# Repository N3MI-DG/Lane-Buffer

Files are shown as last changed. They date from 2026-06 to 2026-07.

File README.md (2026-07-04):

# Lane Buffer for Boxturtle
An inline filament buffer for toolchangers integrated into the rear skirts of the Boxturtle.

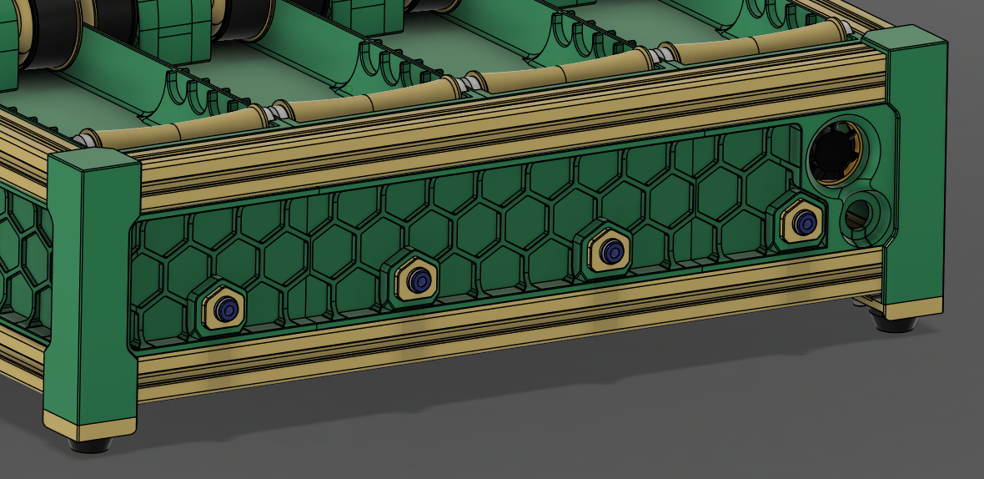
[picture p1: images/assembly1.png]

<br/>
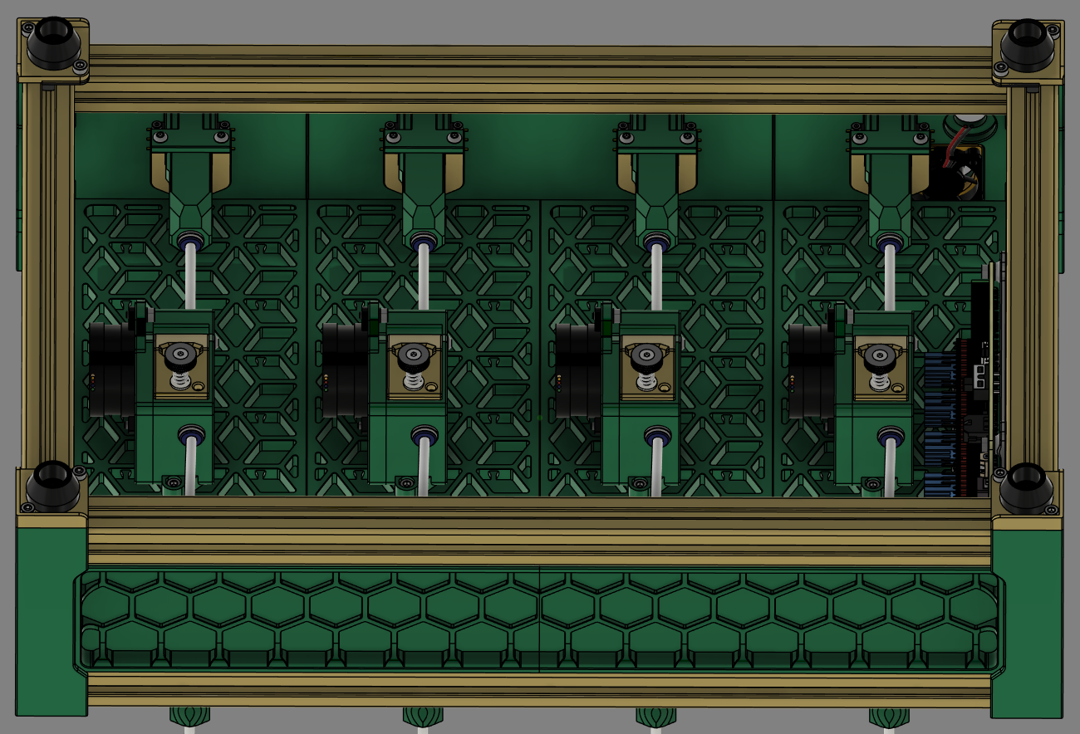
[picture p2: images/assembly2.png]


## Hardware BOM (Per Lane)

- ECAS04 Bowden Coupler x2
- M3 Heat Insert x2
- M3x20 BHCS x2
- M3x40 SHCS (Half Thread) x1
- M2x10 Self Tapping screws x4
- M3 Washer x1
- D2F-5L Switch x2
- Pen Spring (~29mm long, I sourced mine from a BIC 4 pen)
- 4mmx2mm Bowden Tube (114mm long)
- Wire and JST Connectors for 2 switches

## Printed BOM

- Switch Mount (x1 per lane)
- Hex Insert (x1 per lane)
- Clip (x1 per lane)
- Slide (x1 per lane)
- Alignment Jig
- Rear Skirt End
- Rear Skirt Center
- Rear Skirt Power

## Instructions (Per Lane)

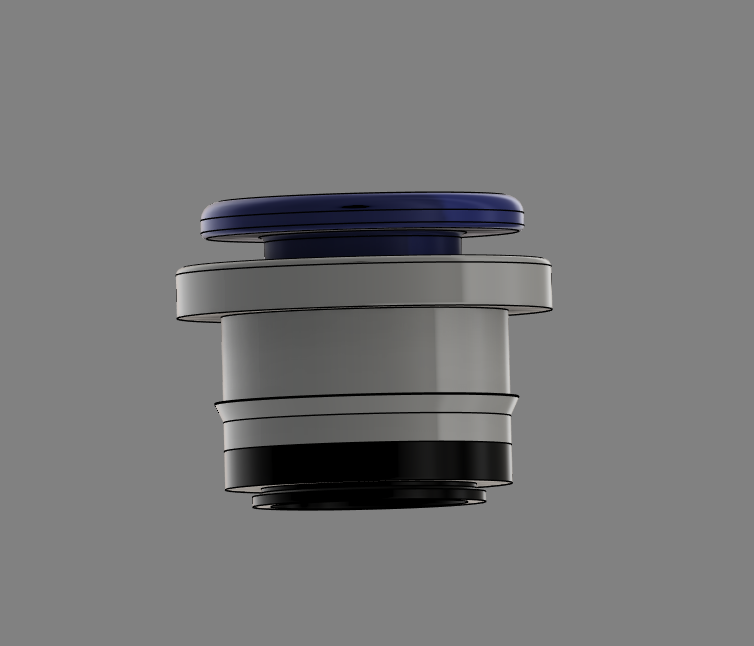
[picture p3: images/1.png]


- Remove the rubber piece from the ECAS04 couplers and discard them. They are not required for this build.

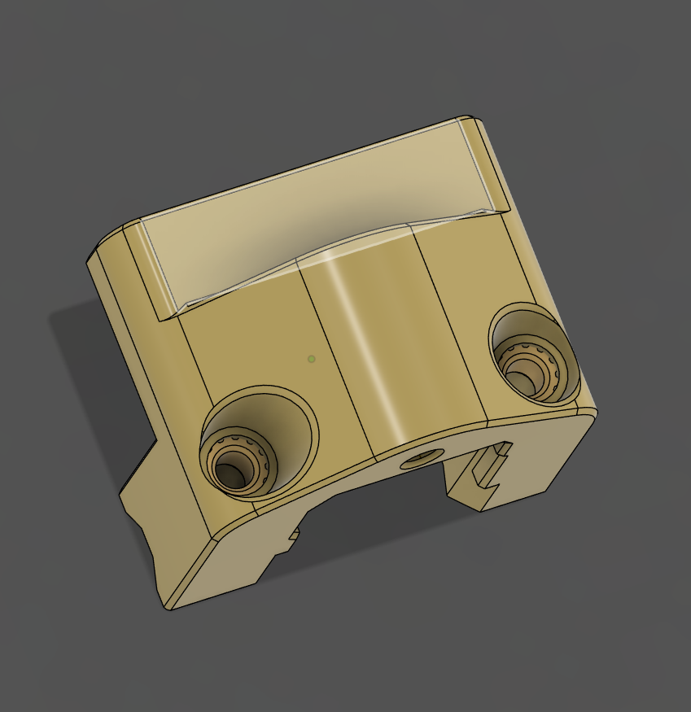
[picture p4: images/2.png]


- Install the 2 M3 heat inserts into the Switch Mount.

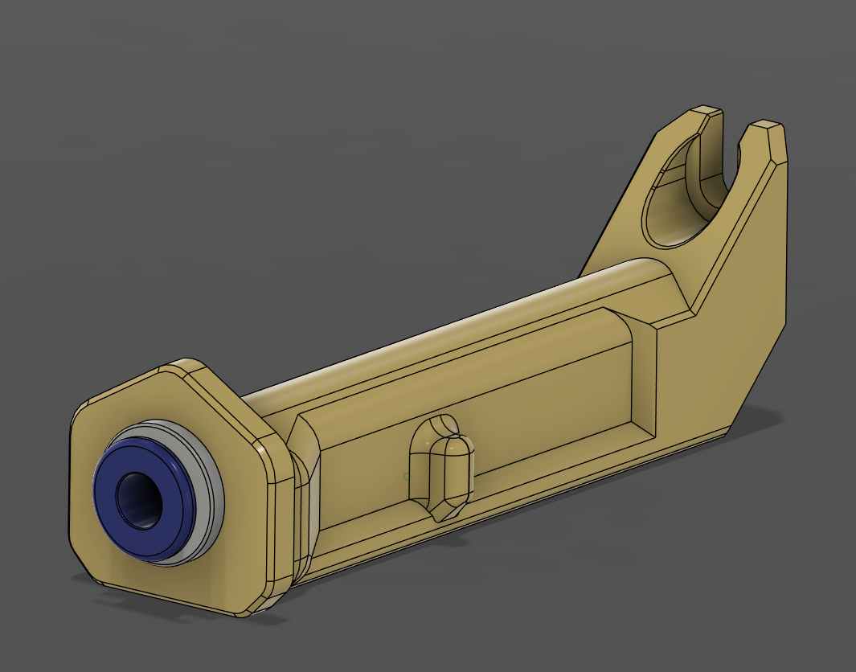
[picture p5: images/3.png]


- Install the ECAS04 into the Slide.

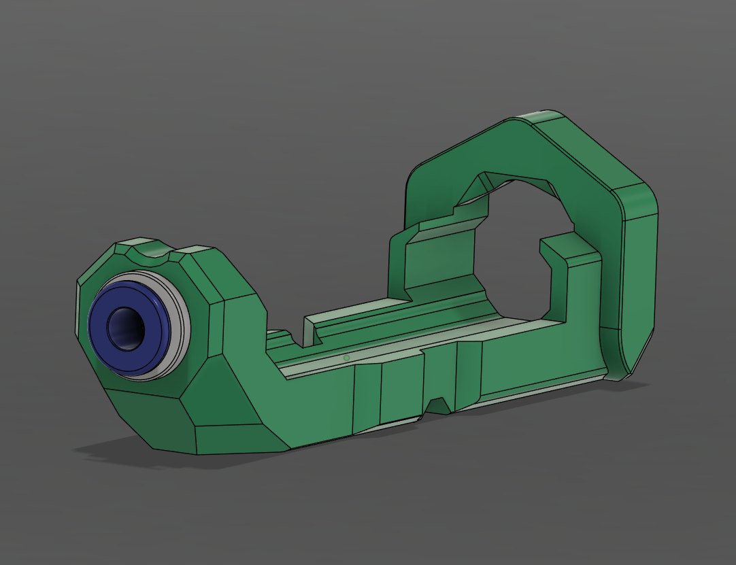
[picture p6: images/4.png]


- Install the ECAS04 into the Hex Insert.

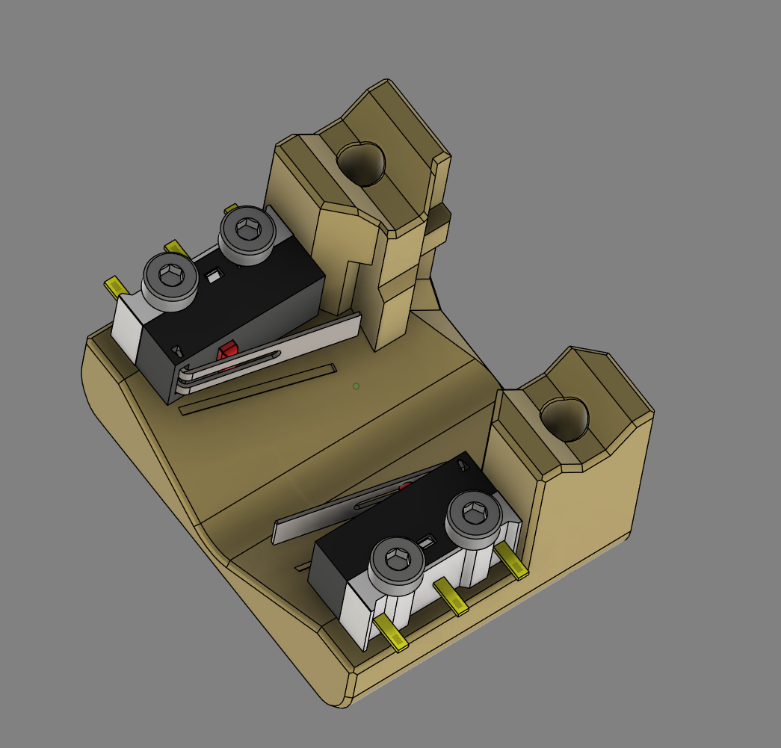
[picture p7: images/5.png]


- Attach the 2 D2F-5L switches to the Switch Mount with the lever in the orientation marked on the print.

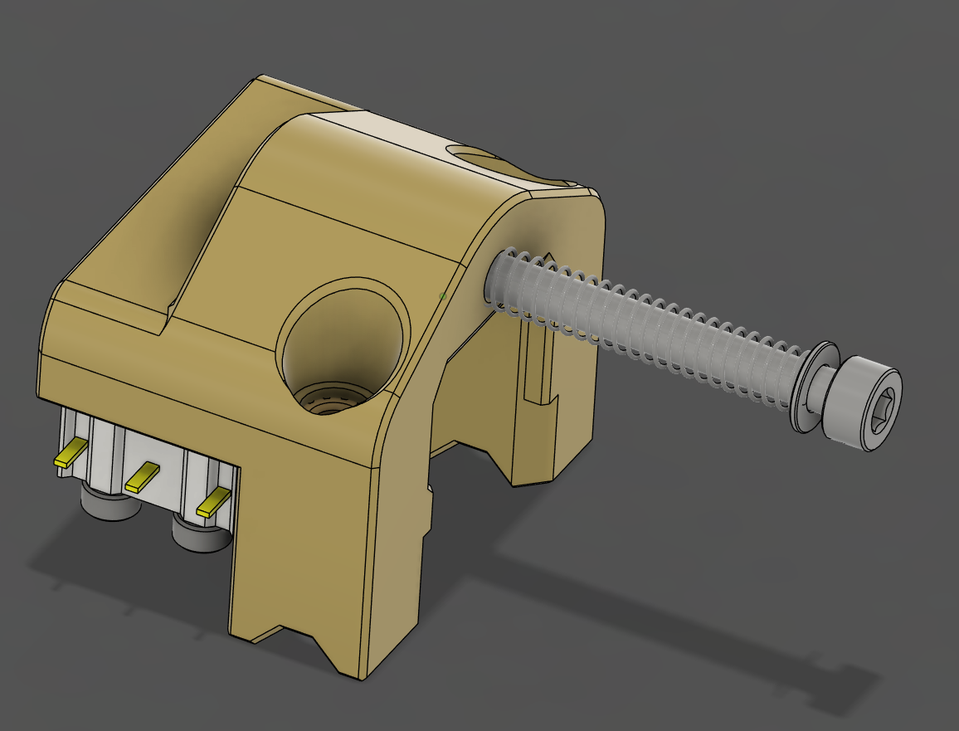
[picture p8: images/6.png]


- Place a M3 washer and pen spring over the M3x40 SHCS (Half Thread) and screw it in to the Switch Mount. There should be ~20mm of the bolt's shaft exposed.

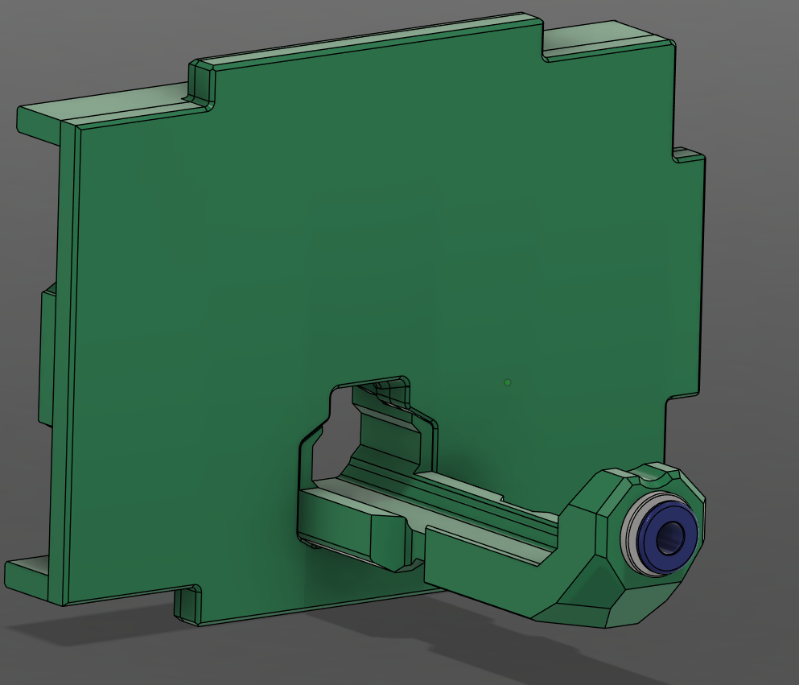
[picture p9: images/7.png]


- Place the Hex Insert through the hole in the skirt piece. It needs to be angled in to make the ECAS section clear.

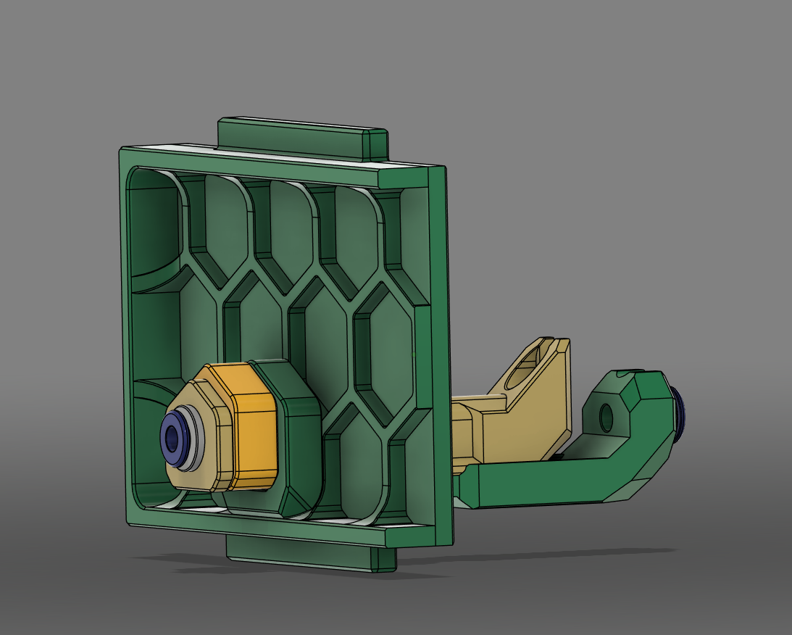
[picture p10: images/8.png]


- Place the Slide through the hole in the Hex Insert and attach the Alignment Jig. It needs to be angled in.

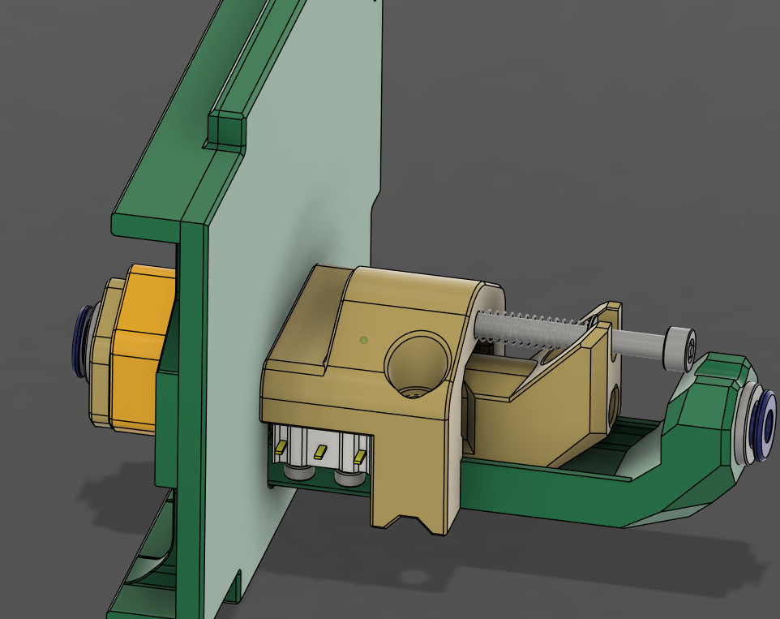
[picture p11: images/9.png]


- Place the Switch Mount Assembly over the Slide and Hex Insert ensuring the washer and spring sit inside the relief in the Slide and the switch's levers do not get caught on the Slide's dimples.

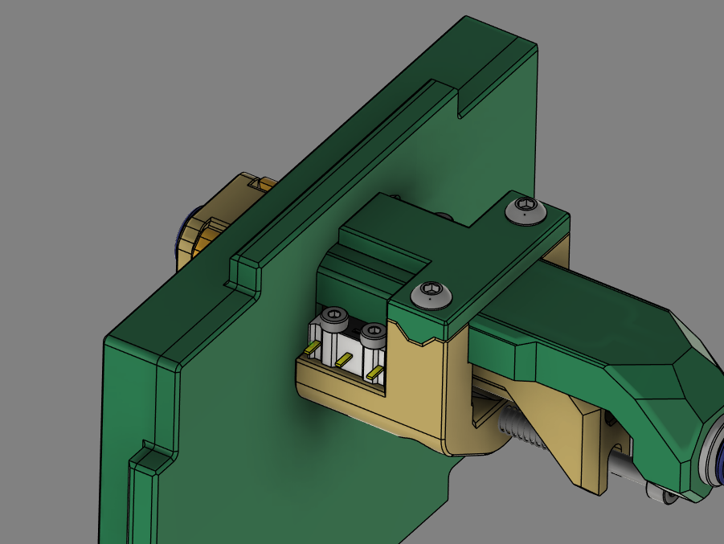
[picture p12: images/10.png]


- Attach the clamp to the bottom of the assembly using 2 M3x20 BHCS screws.

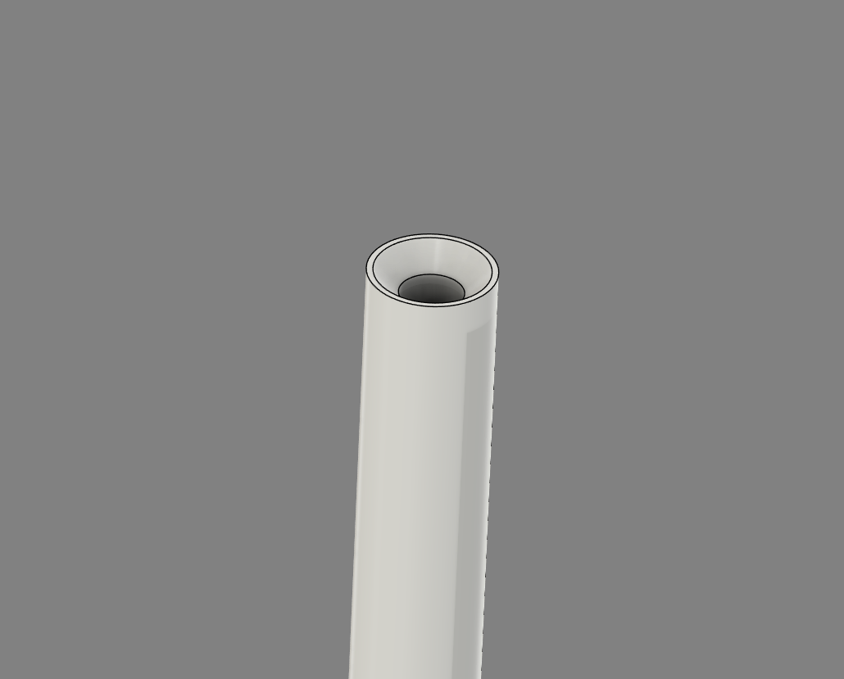
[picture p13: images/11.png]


- Cut a Piece of 4mmx2mm bowden tube 114mm long and chamfer the inside of one end. Make the the bowden piece as straight as possible.

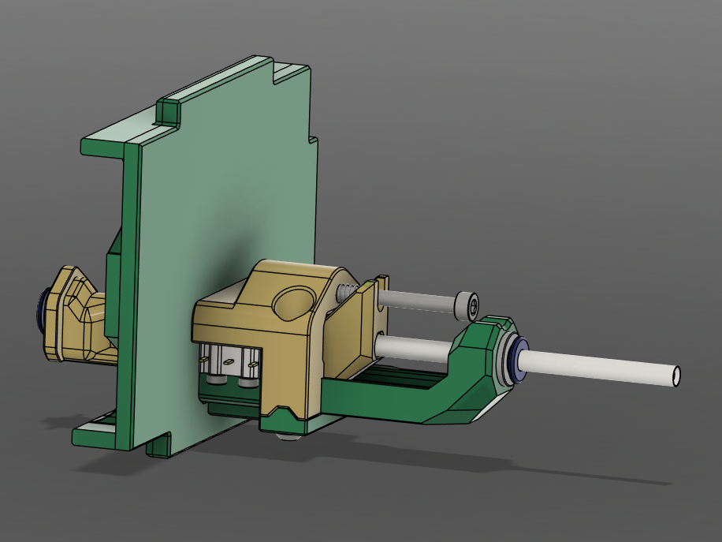
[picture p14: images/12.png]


- Insert the 4x2mm bowden tube pushing it in as far as it wil go. This will compress the spring and hold the slide in the "extended" position. Remove the Alignment Jig while the spring is compressed.

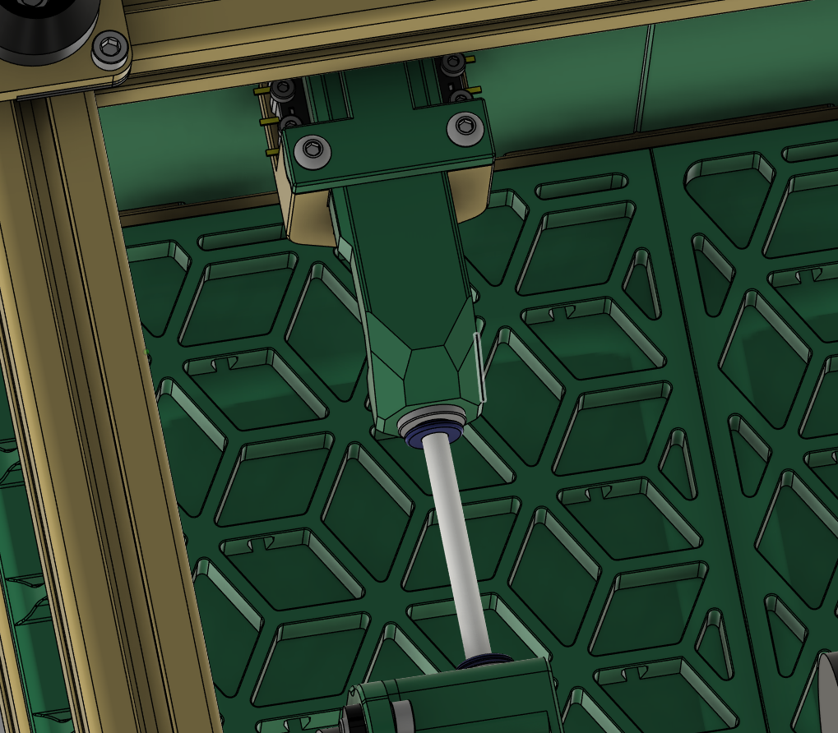
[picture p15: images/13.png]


- After installing the skirt/buffer assemblies in to the BoxTurtle, depress the ECAS coupler on the Hex Insert and Pull the bowden tube out and seat it in to the ECAS coupler on the lane's extruder.

---
## Wiring

- Good luck.
---
## Credits

[Armoured Turtle](https://github.com/ArmoredTurtle) - Original Rear Skirts and Turtle Neck Buffer which were used for reference.

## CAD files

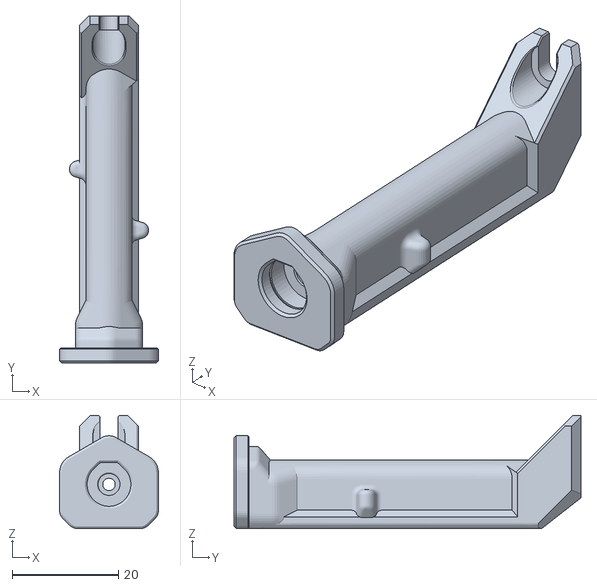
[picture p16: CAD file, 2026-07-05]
STL/Buffer/[a]_Slide_xN.stl
18.6 x 65.4 x 21.3

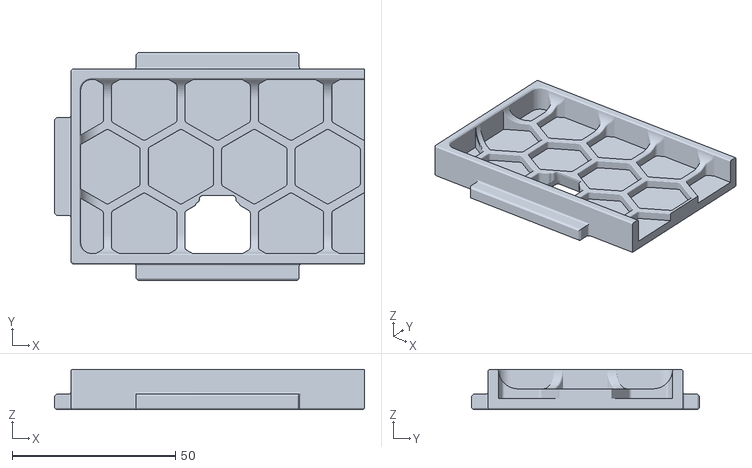
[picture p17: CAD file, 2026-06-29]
STL/Skirts/Rear_Skirt_End.stl
95.0 x 69.8 x 12.4

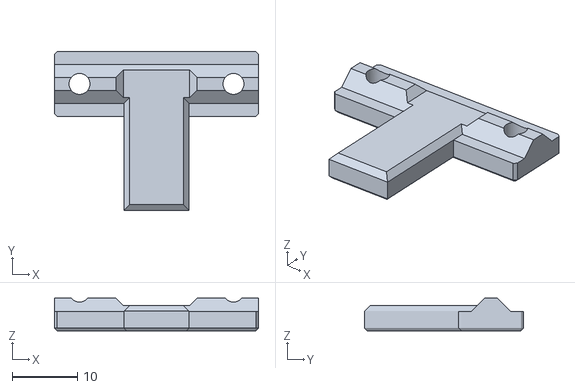
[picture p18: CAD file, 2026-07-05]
STL/Buffer/Clamp_xN.stl
31.2 x 24.3 x 4.99

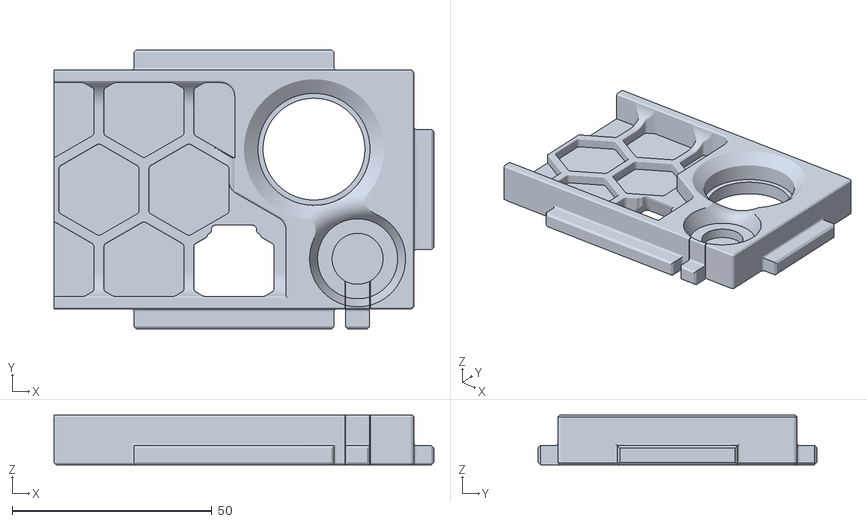
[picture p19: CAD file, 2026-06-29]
STL/Skirts/Rear_Skirt_Power.stl
95.0 x 69.8 x 12.4

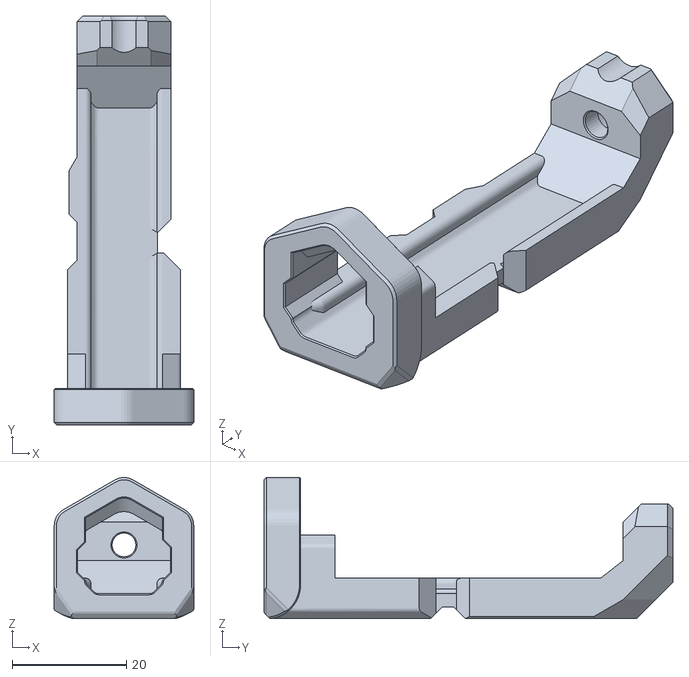
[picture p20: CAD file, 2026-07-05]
STL/Buffer/Hex_Insert_xN.stl
24.4 x 71.5 x 24.7

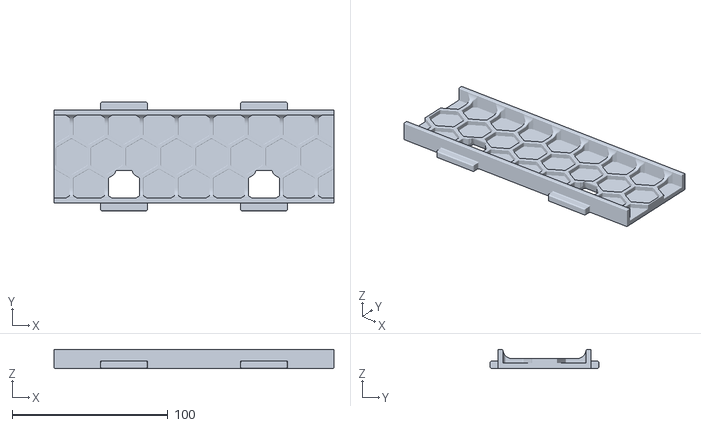
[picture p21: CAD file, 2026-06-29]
STL/Skirts/Rear_Skirt_Center.stl
180.0 x 69.8 x 12.4

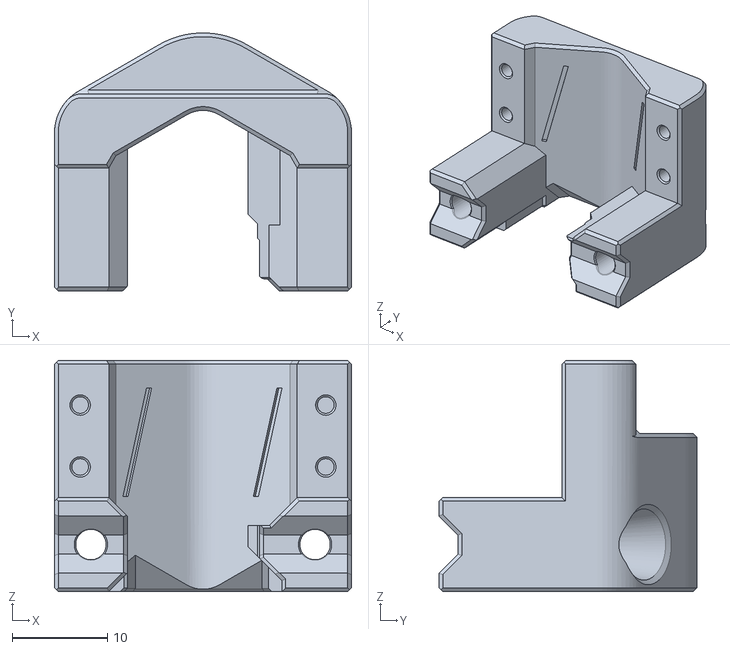
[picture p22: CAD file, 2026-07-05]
STL/Buffer/[a]_Switch_Mount_xN.stl
31.2 x 27.1 x 24.3

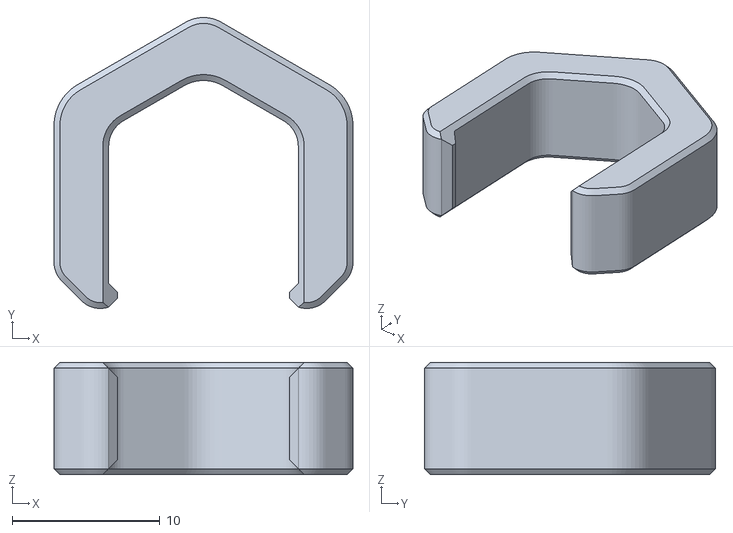
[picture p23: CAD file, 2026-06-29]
STL/Buffer/Alignment_Jig.stl
20.2 x 19.7 x 7.60

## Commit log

2026-07-04 Screw should be 40mm
2026-07-05 Refined some clearances
    [Clamp_xN.stl, Hex_Insert_xN.stl, [a]_Slide_xN.stl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]
